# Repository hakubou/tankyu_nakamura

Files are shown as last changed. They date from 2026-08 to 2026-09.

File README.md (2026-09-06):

# 回転型倒立振子（Furuta pendulum）

Damiao **DM-J4310-2EC V1.1** と Quanser **QUBE-Servo 2** の振子モジュールを組み合わせた
回転型倒立振子。振り上げ（スイングアップ）から倒立保持までを自動で行う。

学校の探究課題として 2026 年 8 月に製作したもの。

## 到達点（2026-08-28 時点）

| 項目 | 実績 |
|---|---|
| スイングアップ成功率 | **82.8%**（トルク上限 0.8 N·m、29 回） |
| 振り上げ所要時間 | 中央値 1〜2 秒 |
| 倒立保持 | **最長 61.6 秒**（スイングアップからの連続動作） |
| 失敗の内訳 | すべて「アーム角が ±140° に到達」。**振子の姿勢制御自体の失敗は 0 件** |

制御周期は約 600 Hz。振子角は STM32 のハードウェアエンコーダで読み、
13 バイトのフレームで PC へ 1 kHz 送信する。制御則（オブザーバ＋LQR、
エネルギー整形則によるスイングアップ）はすべて PC 側の C# で動く。

## 構成

```
model/                          運動方程式の導出と制御則の設計（Python・オフライン専用）
  furuta_model.py                 SymPy による Lagrange 法の導出、線形化
  design_and_simulate.py          LQR / カルマンゲインの設計、非理想要素込みの検証
  friction_study.py               Karnopp 摩擦モデルでの検討
  pendulum_identification.py      振子パラメータの同定
  FurutaGains.cs                  ★生成物。csharp/src/DamiaoCan/ へコピーして使う

モータ制御プログラム一式_20260806/
  csharp/src/
    DamiaoCan/                    ライブラリ本体（CAN プロトコル、MIT フレーム、スケーリング）
    SwingUp/                      ★振り上げ→キャッチ→倒立保持
    BalanceControl/               ★倒立保持のみ
    PendulumTelemetry/            受信・状態推定の確認（トルクは送らない）
    SignCalibration/              座標系の符号を実測で決める
    FrictionTest/ TorqueCalibration/ OpenLoopSwing/ ほか  同定・校正ツール
  csharp/tests/DamiaoCan.Tests/   88 件。実機なしで通る

機構/                            アダプタの STL と生成スクリプト
引き継ぎ_20260828/
  01_引継ぎメモ_20260828.md       ★本体。経緯・設計・実測値・つまずいた点の全記録
  動作確認済みコード_20260828/     実機で動作を確認した版のスナップショット
  マイコンスケッチ/                STM32（Arduino）側。エンコーダを読んで送るだけ

ポスター/
  倒立振子_A0ポスター.html         ★発表用ポスター（A0 縦）。ブラウザで開いてそのまま印刷できる
  倒立振子_ポスターレイアウト案.html  面積配分を決めたワイヤーフレーム
```

## 動かす

`.NET SDK 10.0` が必要。

```
cd モータ制御プログラム一式_20260806/csharp
dotnet build
dotnet test
dotnet run --project src/SwingUp -- COM4 COM8 30 1.0 25 10
```

引数は左から「振子ポート・モータポート・SwingGain・振り上げトルク上限・
キャッチ角度・最小射影法の c・保持秒数」。**COM ポート番号は環境ごとに変わる。**

`model/FurutaGains.cs` を再生成したら、`csharp/src/DamiaoCan/` へのコピーが毎回必要。

## 実測した主なパラメータ

| 記号 | 値 | 備考 |
|---|---|---|
| J_r | 2.13×10⁻³ kg·m² | アーム慣性。高周波・小振幅加振で同定。質量からの概算の 5.3 倍で、差は減速機の反射ロータ慣性 |
| τ_c | 0.109 / 0.143 N·m | クーロン摩擦（正転／逆転）。30% の非対称あり |
| b_r | 0.027 N·m·s/rad | アーム側の粘性 |
| 振子の固有振動数 | 1.70 Hz | 実測。モデル予測 1.746 Hz と 3% 以内で一致 |
| 不安定極 | 11.05 rad/s | 時定数 90 ms |

## 設計上の方針

- 制御の実装はすべて **C#（.NET 10）**。Python は運動方程式の導出とゲイン計算のみに使い、
  **成果物は数値行列として C# に定数で埋め込む**。実行時に Python を呼ばない
- マイコン側は **エンコーダを読んで送るだけ**。制御ロジックは載せない
- MIT モードで `kp=kd=0` とし、`t_ff` だけでトルクを与える純トルク制御

## 安全上の注意

- **アームを 1 回転させない**（配線が引っ掛かる）
- 実行前にアームと振子の可動範囲に物・手・ケーブルが無いことを確認する
- 電源スイッチにすぐ手が届く状態で実行する
- 実行中に他のウィンドウをクリックすると、Windows の電源スロットリングで
  制御周期が 575 Hz → 130 Hz に落ちる。**計測中は裏で何も動かさない**

## ライセンス・帰属

- QUBE-Servo 2 の振子モジュールは借用品
- 引き継ぎ資料中の人名は伏せてある（メンバー A / B / C・指導教員）

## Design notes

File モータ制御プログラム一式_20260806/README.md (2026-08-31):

# DM-J4310-2EC V1.1 を Python から動かす手順

2026/8/6 に動作確認済み。同じ手順で誰でも再現できます。
不明点はメンバーA（<学籍番号>）まで。

---

## これは何か

Damiao のモータ **DM-J4310-2EC V1.1** を、PCから CAN 通信で回すためのプログラムです。
公式ソフト（達妙調試助手）は配布元が 404 で入手できなかったため、
**Python から直接 CAN フレームを送受信する方式**で実現しています。

実測: 速度モードで 0.5 rad/s を指定し、12.6秒で **359.5〜359.6度（＝1.00回転）**。
速度のばらつきはほぼ無し。

---

## 必要なもの

### ハードウェア

| 品目 | 備考 |
|---|---|
| DM-J4310-2EC V1.1 モータ | CAN ID は今回 **4** に設定済み |
| 24V 直流電源 | OMRON S8FS-G24024（240W級）を使用。8〜10A あれば十分 |
| USB-CAN 変換 | USB-CAN Analyzer V8.00（120Ω終端が内蔵されている） |
| 配線 | XT30(2+2) ケーブル（モータに付属） |

### 配線

```
        ┌── VCC / GND ──→ 24V電源
モータ ─┤  (XT30(2+2))
        └── CAN_H / CAN_L ──→ USB-CAN変換 ──USB──→ PC
```

※ GND は電源側と USB-CAN 側で共通にすること。

### ソフトウェア

```bash
pip install python-can pyserial
```

Python 3.14.6 で確認。CH340 のドライバが必要ですが、Windows 11 なら
USB-CAN を挿すと自動で入ることが多いです。

---

## 動かす手順

### 1. COMポート番号を調べる

デバイスマネージャー →「ポート (COM と LPT)」に
`USB-SERIAL CH340 (COM3)` のように表示されます。**この番号を控えてください。**
表示されない場合はドライバが入っていません。

### 2. 設定を自分の環境に合わせる

`demo_1回転.py` の冒頭を書き換えます。

```python
PORT     = "COM3"    # ← 手順1で調べた番号
MOTOR_ID = 4         # ← モータのCAN ID
```

### 3. 安全確認（必ず）

- モータが固定されているか
- 出力軸の回転範囲に手・物・ケーブルが無いか
- 電源スイッチにすぐ手が届くか

### 4. 実行

```bash
py demo_1回転.py
```

通信確認 → モード確認 → 1回転、まで自動で行います。

---

## つまずきポイント（先に読んでおくと時間を節約できます）

### 動かないときは、まず 24V 電源を疑う

**一番時間を無駄にした原因がこれです。** 電源が入っていないのに
「Enable が効かない」と悩み続けました。
モータのLEDが**赤＝失能、緑＝使能（通電中）**なので、まずLEDを見てください。

### MITモードでは kp を 0 にしてはいけない

`kp = 0` だと力が発生せず、モータはまったく動きません。
指令は届いていて、フィードバックも返ってくるのに動かないので原因が分かりにくいです。
今回は `kp = 20`、`kd = 2.0` で安定しました。

### 目標位置を遠くに置くと急加速する

MITモードで「29度先」を一度に指定したところ、非常に速く動いて危険でした。
目標との差が大きいほど強い力が出るためです。
**目標を5msごとに少しずつ進める**ことで、滑らかな低速回転になります
（`mit_move()` に実装済み）。

### 一定速度で回すだけなら速度モードが楽

| | MITモード | 速度モード |
|---|---|---|
| 指令 | 位置・速度・kp・kd・トルクの5要素 | 速度 (rad/s) のみ |
| 実装 | ゲイン調整と軌道生成が必要 | 値を1つ送るだけ |
| エンコーダ一周時 | 位置が飛んで誤停止した | 影響なし |

制御モードは **CAN経由で変更でき、フラッシュ保存すれば電源を切っても維持されます**
（`set_mode()` に実装済み）。今回は速度モード(3)に設定してあります。

### USB-CAN を開いた直後は 0.5 秒待つ

すぐに送信すると応答を取りこぼします。モジュール側で対処済みです。

### Enable / Disable はモータIDあてに送る

`0x104` や `0x204` に送っても受け付けられません。必ずモータID（今回は `0x004`）へ。

---

## ファイル構成

| ファイル | 内容 |
|---|---|
| `damiao_can.py` | 本体。接続・状態取得・使能/失能・モード読み書き・速度制御・MIT制御 |
| `demo_1回転.py` | 実行用。1回転させるデモ |
| `README.md` | このファイル |

## 簡単な使い方

```python
from damiao_can import Motor

with Motor(port="COM3", motor_id=4) as m:
    print(m.read_status())          # 状態を読む（動かない）
    m.spin(speed=0.5, turns=1.0)    # 0.5 rad/s で1回転
```

`with` を抜けると**必ず失能**されます。途中でエラーが出ても
モータは安全な状態（非通電）に戻るようになっています。

### よく使う操作

```python
m.read_status()                 # 位置・速度・エラー・温度を取得
m.scan()                        # 応答するモータのCAN IDを探す
m.read_mode()                   # 制御モードを確認 (1=MIT, 2=位置速度, 3=速度)
m.set_mode(3)                   # 速度モードへ変更して保存
m.spin(speed=0.5, turns=2.0)    # 2回転
m.spin(speed=-0.5, turns=1.0)   # 逆回転
m.mit_move(delta_rad=1.57)      # MITモードで90度動かす
```

---

## 主な仕様（データシートより）

- 定格 24V / 2.5A、ピーク 7.5A、過電流保護は 9.8A 以下推奨
- 定格トルク 3N·m、ピーク 7N·m、減速比 10:1
- 制御は CAN 1Mbps・標準フレーム
- Enable: `FF FF FF FF FF FF FF FC` / Disable: `FF FF FF FF FF FF FF FD`

詳しい背景や検証の経緯は、報告書 `モータ動作検証報告_20260806.pdf` を参照してください。

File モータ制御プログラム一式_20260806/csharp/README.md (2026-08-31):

# DM-J4310-2EC V1.1 を C# から動かす

研究室の方針に合わせ、Python 版（`../damiao_can.py` / `../demo_1回転.py`）を C# へ移植したものです。
ハードウェアの構成・配線・注意点は Python 版の [`../README.md`](../README.md) と同じなので、
**初めて動かす人は先にそちらを読んでください。**

---

## 必要なもの

### ハードウェア

Python 版とまったく同じです（DM-J4310-2EC V1.1 / 24V電源 / USB-CAN Analyzer V8.00 / XT30(2+2)）。

### ソフトウェア

- .NET SDK 10.0 以降
- CH340 のドライバ（USB-CAN を挿すと Windows 11 なら自動で入ることが多い）

Python も python-can も不要です。CAN アダプタのプロトコルは自前で実装してあります（後述）。

---

## 動かす手順

### 1. COMポート番号を調べる

デバイスマネージャー →「ポート (COM と LPT)」に `USB-SERIAL CH340 (COM3)` のように表示されます。

### 2. 安全確認（必ず）

- 24V電源が入っているか（**動かないときの原因はたいていこれ**）
- モータが固定されているか
- 出力軸の回転範囲に手・物・ケーブルが無いか
- 電源スイッチにすぐ手が届くか

### 3. 実行

```bash
dotnet run --project src/DemoOneTurn -- COM3
```

引数を省略すると `COM3` を使います。macOS / Linux なら `/dev/tty.usbserial-1140` のように指定してください。

通信確認 → モード確認 → 1回転、まで自動で行います。実行中に **Ctrl+C** を押すと、
その場で減速停止してから失能します（プロセスを即座に殺さないようにしてあります）。

### 4. 単体の exe にして配る場合

.NET が入っていないPCでも動く形にまとめられます。

```bash
dotnet publish src/DemoOneTurn -c Release -r win-x64 --self-contained -p:PublishSingleFile=true
```

---

## 簡単な使い方

```csharp
using DamiaoCan;

using var motor = new Motor("COM3", motorId: 4);

Console.WriteLine(motor.ReadStatus());        // 状態を読む（動かない）
motor.Spin(speed: 0.5, turns: 1.0);           // 0.5 rad/s で1回転
```

`using` を抜けると **必ず失能** されます。途中で例外が出てもモータは安全な状態（非通電）に戻ります。

### よく使う操作

| C# | Python 版 |
|---|---|
| `motor.ReadStatus()` | `m.read_status()` |
| `motor.Scan()` | `m.scan()` |
| `motor.ReadMode()` | `m.read_mode()` |
| `motor.SetMode(ControlMode.Velocity)` | `m.set_mode(3)` |
| `motor.Spin(speed: 0.5, turns: 2.0)` | `m.spin(speed=0.5, turns=2.0)` |
| `motor.Spin(speed: -0.5, turns: 1.0)` | `m.spin(speed=-0.5, turns=1.0)` |
| `motor.MitMove(deltaRad: 1.57)` | `m.mit_move(delta_rad=1.57)` |

---

## ファイル構成

| ファイル | 内容 |
|---|---|
| `src/DamiaoCan/Motor.cs` | 本体。使能/失能・状態取得・モード読み書き・速度制御・MIT制御 |
| `src/DamiaoCan/SeeedCanBus.cs` | USB-CAN Analyzer のシリアルプロトコル |
| `src/DamiaoCan/ICanBus.cs` | CANバスの抽象。別アダプタやテスト用の差し替え口 |
| `src/DamiaoCan/MotorFeedback.cs` | モータからの8バイトフィードバックの解釈 |
| `src/DamiaoCan/MotorScaling.cs` | MITフレームの値域と実数⇔整数の換算 |
| `src/DamiaoCan/ControlMode.cs` | 制御モード (1=MIT, 2=位置速度, 3=速度) |
| `src/DemoOneTurn/Program.cs` | 実行用。1回転させるデモ |
| `tests/DamiaoCan.Tests/` | 実機なしで動く検証（後述） |

---

## Python 版からの移植で変えたところ

### python-can に相当するものを自前で実装した

Python 版は `python-can` の `seeedstudio` バックエンドが USB-CAN Analyzer を扱っていましたが、
.NET には同等のライブラリがありません。そこで `SeeedCanBus.cs` に同じシリアルプロトコルを実装しています。

```
初期化   AA 55 12 [速度] [フレーム種別] [フィルタ4B] [マスク4B] [動作モード] 01 00×4 [CRC]
送受信   AA [0xC0|拡張<<5|RTR<<4|DLC] [ID 2B(標準) リトルエンディアン] [データ] 55
状態応答 AA 55 [18バイト]
```

依存は NuGet の `System.IO.Ports` だけです。

### 受信は必ず「まとめ読み」にしてある（重要）

`SerialPort.ReadByte()` は **1 回あたり約 1.16ms** かかります（macOS で実測）。
CAN フレーム 1 本はシリアル 13 バイトなので、Python 版と同じ「1 バイトずつ読む」構造で書くと
**1 本の受信に 15ms** も取られ、200Hz どころか 62Hz しか出ません。

`Read(buffer, 0, n)` でまとめ読みすれば同じ 13 バイトが 0.29ms で取れるので、
`SeeedCanBus.ReadByte()` は内部バッファに一括で貯めてから 1 バイトずつ払い出す作りにしてあります。
**ここを 1 バイト読みに戻すと制御周期が壊れます。**

実測値: 受信 15.08ms → 1.16ms、200Hz ループの実周期 16.3ms → 5.000ms。

### Ctrl+C で安全に止まるようにした

C# は既定だと Ctrl+C でプロセスが即座に終了し、`finally` の失能処理が走りません。
Python 版と同じ安全性を保つため、デモ側で Ctrl+C を捕まえて停止処理へ回しています。
`Spin()` と `MitMove()` は `CancellationToken` を受け取ります。

### 危険な入力を弾くようにした

- `Spin(speed: 0)` に回転数を指定すると、Python では所要時間がゼロ除算になります。
  C# では無限大になって**回り続けてしまう**ため、明示的に例外にしています。
- `MitMove` の速度が 0 以下の場合も同様です。

### CANバスをインターフェースにした

`Motor` は `ICanBus` に依存します。実機なしでテストできるほか、
別のCANアダプタを使う場合や1本のバスに複数台ぶら下げる場合にも差し替えられます。

### rad→deg の換算定数

Python 版は `57.2958`、C# 版は `180/π` を使っています。
差は4回転ぶん回しても 0.001度未満（エンコーダ分解能 0.0004度より小さい）で、実測に影響しません。

---

## 検証

実機が無くても、**Python 版とバイト単位で同じフレームを出すか**を自動で確認できます。

```bash
dotnet test
```

期待値は Python 版（`damiao_can.py` と python-can 4.6.1 の seeedstudio バックエンド）を
実際に走らせて採取したバイト列そのものです。80件すべて合格しています。

検証している範囲:

- アダプタの初期化フレーム（CRC 含む）
- 使能 / 失能 / 速度指令 / モード読み書き / フラッシュ保存の各パケット
- MITフレームの詰め方（値域外の頭打ちを含む）
- フィードバックの解釈と位置の rad 換算
- 受信パースの復帰（ゴミバイト・状態応答パケット・壊れたフレーム）
- エンコーダが一周したときの差分補正
- 例外や中断が起きても最後に必ず失能を送ること

**実機での動作確認はまだ行っていません。** 上記はあくまで「Python 版と同じバイト列を出す」ことの
確認までです。初回はモータを固定し、電源スイッチに手を届く状態で試してください。

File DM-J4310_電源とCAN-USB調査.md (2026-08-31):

# DM-J4310-2EC V1.1 — 電源(24V)とCAN-USB変換 調査メモ

対象モーター: DAMIAO（达妙）**DM-J4310-2EC V1.1**（QDDサーボ関節モーター / 24V版）
作成日: 2026-07-06

---

## 1. まとめ（結論）

| 項目 | 推奨・目安 |
|---|---|
| 電源電圧 | **24V**（動作範囲 15〜32V） |
| 電源電流（1個・実用） | **最低 3A、余裕をもって 5〜10A** を推奨 |
| 電源電流（1個・ピーク吸収） | 瞬間 7.5A まで流れうる → **10A級電源**が安心 |
| CAN-USB変換 | **DAMIAO純正 USB-to-CAN（USB2CAN）モジュール**が最も確実 |
| CANボーレート | **1 Mbps 固定**（標準フレーム） |
| 終端抵抗 | CANバス両端に **120Ω** |

---

## 2. 24V電源に必要な電流

### 2.1 モーター単体の消費電流

公式・代理店資料の数値（24V版）:

| 電流の種類 | 値 | 備考 |
|---|-----|---|
| **定格電流（電源側 / バス電流）** | **2.5 A** | 定格トルク3N·m時の目安 |
| **ピーク電流（電源側）** | **7.5 A** | 瞬間・加速/急停止時 |
| 定格相電流（Rated Phase Current） | 3.7 A | モーター巻線に流れる電流 |
| ピーク相電流（Peak Phase Current） | 7.2 A | 巻線ピーク |

> ⚠️ 「相電流（phase current）」と「電源電流（bus current）」は別物です。
> 電源（ACアダプタ/安定化電源）の容量選定には、**電源側の電流（定格2.5A / ピーク7.5A）** を使います。

### 2.2 電力に換算

- 定格: 24V × 2.5A ≒ **60 W**
- ピーク: 24V × 7.5A ≒ **180 W**

### 2.3 電源容量の選び方（推奨）

**モーター1個の場合**
- 動作確認・デバッグ用途: **24V / 3〜5A（72〜120W）** で可
- 負荷をかけた運用: 突入・加速でピークが出るため **24V / 10A（240W）** クラスが安心
  - 安価な安定化電源やベンチ電源なら「24V 10A」表記のものが定番

**複数個（ロボットアーム等）の場合**
- 最悪ケース = ピーク電流の合計: `モーター数 × 7.5A`
  - 例）4軸アーム → 4 × 7.5A = 30A（＝ 24V 30A ≒ 720W）
  - 例）6軸アーム → 6 × 7.5A = 45A
- 実際は全軸が同時に最大ピークになることは稀なので、
  現実的には **「定格合計 ＋ 余裕」** で設計することが多い:
  - 例）6軸 → 定格 6 × 2.5A = 15A → **24V 20A（480W）** 程度を選定し、大電流の瞬間はコンデンサ/電源のマージンで吸収
- **重要（公式ガイダンス）**: 複数モーターでは**専用の電源分配基板（Power Board）を用意し、制御PC/Jetson等の電源とモーター電源を分離**すること。

### 2.4 その他の電気的注意

- 過電圧保護: 推奨 **32V以下**
- 低電圧保護: 推奨 **15V以上**
- 過電流保護: 推奨 **9.8A以下**
- 温度保護: ドライバ 120℃ / コイル 推奨100℃以下
- 48V版も存在（動作範囲15〜52V）。24V版とは別品番なので購入時に要確認。

---

## 3. CAN-USB変換（上位機との接続）

### 3.1 通信仕様

- 制御インターフェース: **CAN @ 1 Mbps（標準フレーム、ボーレート固定）**
- パラメータ設定インターフェース: **UART @ 921600 bps**
- 制御モード: MITモード / 速度モード / 位置モード（台形加減速対応）

### 3.2 変換機の選択肢

#### (A) DAMIAO純正 USB-to-CAN（USB2CAN）モジュール ★推奨
- モーターと同時購入できる純正デバッグツール
- 超小型（約 **39 × 18 mm**）、64KB オンボードバッファ、CANアナライザ機能内蔵
- ボーレート 1000 kbps〜（可変）、タイマ送信対応
- Windows用「**DAMIAO デバッグアシスタント（上位机 / Debugging Assistant）**」で
  ID設定・モード切替・モニタリングが可能
- USB↔UART変換も兼ねるため、パラメータ設定（921600bps）にも使える

#### (B) 汎用USB-CANアダプタ
- **CANable 2.0 / candleLight系**（Linuxのsocketcanで `can0` として使える）
  - `slcan` またはネイティブ candleLight ファームで動作
- **CAN FD対応アダプタ**（LeRobot/OpenArms構成では CAN FD を使用）
- 中華系「USB-CAN / USB2CAN アナライザ」も可（ドライバ・ボーレート設定に注意）

### 3.3 物理接続（純正モジュールの例）

DAMIAOのデバッグツールを使う典型的な配線:

1. **電源＋CAN通信端子**: モーター側の **XT30(2+2)-F** コネクタケーブルで
   USB-to-CANツールへ接続（電源とCAN-H/CAN-Lが一体化したコネクタ）
2. **デバッグ用シリアル（UART）**: **GH1.25 3ピン**ケーブルでシリアルポートを接続
3. **24V電源**: モーターへ別途供給（XT30側の電源ラインへ）
4. USBをPCへ接続 → デバッグアシスタントを起動 → 該当シリアルポートを選択 → 通電

> ⚠️ **H/L反転の注意**: 一部ホスト基板（例: Seeed reComputer Mini）では
> CAN-H / CAN-L のピン配置がモーター側と逆になっている。接続不良時は H/L の入替を確認。

### 3.4 CANバス配線の基本

- **CAN-H / CAN-L / GND** の3線を各モーターへデイジーチェーン接続
- バスの**両端に120Ωの終端抵抗**（片側はアダプタ内蔵の場合あり）
- 複数モーターは **CAN IDを重複しないよう個別設定**（純正ツールで設定）
  - OpenArms/LeRobotの慣例: 送信ID `0x0N` / 受信ID `0x1N`（N=関節番号）

### 3.5 Linux（socketcan）での設定例（LeRobot/OpenArms）

```bash
# can-utils をインストール
sudo apt-get install can-utils

# CAN FD（推奨 / OpenArms）
sudo ip link set can0 down
sudo ip link set can0 type can bitrate 1000000 dbitrate 5000000 fd on
sudo ip link set can0 up

# 通常CAN（FDなし）
sudo ip link set can0 type can bitrate 1000000
sudo ip link set can0 up

# 疎通確認
candump can0
```

- Windowsは純正「デバッグアシスタント（上位机）」でGUI操作が容易
- LeRobotのDamiao対応は**現状Linuxのみ**（OpenArms用CANアダプタのドライバがLinux専用）

---

## 4. 購入時のチェックリスト

- [ ] モーターの電圧版（**24V** or 48V）を確認
- [ ] 24V電源: 1個なら **24V 5〜10A**、多軸なら電流を積算して選定
- [ ] **電源分配基板**（多軸時）と制御系電源の分離
- [ ] **USB-to-CANモジュール**（純正 or CANable等）
- [ ] **XT30(2+2)** 電源+CANケーブル、**GH1.25 3ピン** UARTケーブル
- [ ] **120Ω終端抵抗**（バス両端）
- [ ] Windows: デバッグアシスタント / Linux: can-utils・socketcan

---

## 5. 参考文献

- [DAMIAO 公式製品ページ DM-J4310-2EC V1.1](https://damiao.enactic.ai/products/hardware/dm-j4310-2ec-v1.1/)
- [DM-J4310-2EC V1.1 減速モーター ユーザーマニュアル V1.0 (PDF, Seeed)](https://files.seeedstudio.com/products/Damiao/DM-J4310-en.pdf)
- [DM-J4310-2EC V1.1 Gear Motor User Manual V1.0 (PDF, sharingwin)](https://sharingwin.com/wp-content/uploads/2025/09/DM-J4310-2EC-V1.1-Gear-Motor-User-Manual-V1.0.pdf)
- [Damiao Series Motors — Seeed Studio Wiki](https://wiki.seeedstudio.com/damiao_series/)
- [Damiao Motors and CAN Bus — Hugging Face / LeRobot](https://huggingface.co/docs/lerobot/damiao)
- [DAMIAO Brushless Servo Joint Motor Debugger USB to CAN MIT Module — OpenELAB](https://openelab.io/products/damiao-brushless-servo-usb-can)
- [DAMIAO CAN Debugger USB-to-CAN — Foxtech](https://store.foxtech.com/can-debugger-usb-to-can-communication-debug-tool-for-mit-servo-motors/)
- [DAMIAO DM-J4310-2EC — AIFITLAB（仕様・24V/48V版）](https://aifitlab.com/products/damiao-dm-j4310-2ec-v1-1-servo-motor)
- [USB to CAN FD Converter (Canable 2.0ベース) — Amazon](https://www.amazon.com/Converter-Adapter-Based-Canable-Supports/dp/B0F9F9J3WN)

> 注: 電流値・接続仕様は代理店/版により表記差があります。実機導入時は必ず付属の
> 最新ユーザーマニュアルと安全定格を確認してください。

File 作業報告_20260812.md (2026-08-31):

# 作業報告 2026/08/12（水）

**件名**: DM-J4310-2EC を用いた回転型倒立振子（Furuta pendulum）

ロードマップ上の **Day 2 を完了し、Day 3 を前倒しで完了**した。
あわせて機構設計（アダプタ・校正治具）と振子パラメータの同定まで進んだ。

---

## 1. 実機作業（モータ）

| 項目 | 結果 |
|---|---|
| MIT モードへ移行 | 完了。フラッシュ保存し、電源再投入後も `CTRL_MODE=1` を維持 |
| レジスタ照合 | `P_MAX=12.5` / `V_MAX=30` / 減速比 `10:1` を CAN 経由で直読し、コードの定数と一致を確認 |
| **T_MAX 変更** | **10 → 2.0 N·m**。12bit 分解能が 4.9 → **0.98 mN·m** と5倍細かくなった |
| 逆駆動テスト | 合格。失能時と使能時（トルク0）で感触に差が無く、寄生トルクなし |
| 静止摩擦 | **0.147 N·m**（T_MAX 変更後に再測して 0.137、7%以内で整合） |
| 動摩擦 | **0.126 N·m**（正転 0.109 / 逆転 0.143、30% 非対称） |
| 粘性摩擦 | **0.027 N·m·s/rad** |
| 制御周期 | **300 Hz に決定**（下表） |

### 制御周期の実測（素のモータ、各12秒）

| 目標 | 実測平均 | 標準偏差 | 95%点 | 最大 | 取りこぼし |
|---|---|---|---|---|---|
| 200 Hz | 5.000 ms | 0.820 | 5.92 | 21.7 | 0% |
| **300 Hz ←採用** | **3.333 ms** | **0.563** | **3.75** | 21.8 | 0% |
| 400 Hz | 2.500 ms | 0.851 | 3.61 | 33.1 | 0% |
| 500 Hz | 2.294 ms ✗ | 1.158 | 3.52 | 38.3 | 0% |

500 Hz は追いつけず実質 436 Hz。**USB-CAN の往復遅延が約 2.3 ms** で、これが上限を決めている。
振子の時定数（約 90 ms）に対して常用遅延 5 ms は 6% であり、制御上問題ない。

### T_MAX 変更の検証方法

レジスタを書き換えただけでは、指令とフィードバックの解釈が本当に整合しているか分からない。
そこで**既に測ってある静止摩擦を測り直し**、同じ物理量が同じ値で出るかを確認した。
不整合なら 5 倍または 1/5 倍にずれるはずのところ、0.147 → 0.137 と 7% 以内で一致したため整合と判断。
副次的に、測定のばらつきが 0.133〜0.147 → 0.122〜0.129 と狭まり、分解能向上が実測精度にも表れた。

**変更はモータ側 → コード側の順で行った。** 逆順だと「コードは小さい T_MAX、モータは大きい T_MAX」
となり、同じ指令値が数倍のトルクとして解釈されて危険なため。

---

## 2. 制御ソフト（C# / .NET 10）

### ライブラリに追加したもの

| API | 内容 |
|---|---|
| `Motor.TorqueCommand(torqueNm)` | 純粋トルク指令。`kp=kd=0` を型で保証 |
| `Motor.ReadFeedback(timeout)` | 定周期ループ用のフィードバック読み出し |
| `Motor.ReadParameter / ReadParameterSingle / ReadParameterUInt32` | レジスタ読み出しの汎用化 |
| `Motor.WriteParameterSingle / SaveToFlash` | レジスタ書き込みとフラッシュ保存 |
| `Motor.VerifyScaling()` | **トルクを出す前にレジスタと定数の一致を検証する安全網** |
| `RegisterId` | パラメータ番号の定義（7〜23） |

### 設計上の修正

`Motor.BuildMitFrame` がグローバル定数（`MotorScaling`）に暗黙依存していたため、
T_MAX を変更すると「Python 版と同じバイト列を出す」という回帰テストの前提ごと壊れた。
**値域を引数で渡せるようにし、詰め方の検証と値域設定を分離**した。

### 作成したツール

| ツール | 用途 |
|---|---|
| `SetControlMode` | モード確認・変更、レジスタ照合、T_MAX 変更 |
| `BackdriveTest` | 逆駆動テスト、制御周期のジッタ計測 |
| `FrictionTest` | 静止摩擦 / 動摩擦・粘性の測定（3モード） |
| `TorqueCalibration` | トルクスケール校正、重力補償デモ（未実行） |

**単体テスト 88 件すべて合格。**

---

## 3. モデリングと制御設計

### 実施内容

- **SymPy による Furuta の運動方程式導出**（手計算では Coriolis 項の符号を誤るため）
- 平衡点での線形化 `A`, `B`。可制御性ランク 4/4
- LQR（Bryson の法則）と定常カルマンフィルタの設計
- **実測の遅延・ジッタ・量子化・非対称クーロン摩擦をすべて入れた非線形閉ループ検証**
- 摩擦モデルを `tanh` から **Karnopp（真の固着あり）** に差し替えた再検証
- 摩擦補償の効き・アーム慣性についての感度解析

### 振子パラメータの同定（実測から）

| パラメータ | 値 | 出所 |
|---|---|---|
| 振子全長 | 128.70 mm | 実測 |
| ピボットより上 | 7.0 mm | 実測 |
| **l_p（ピボット→重心）** | **57.35 mm** | 上記から算出 |
| **J_pivot** | **1.123×10⁻⁴ kg·m²** | 自由振動 T=0.5730 s から |
| **J_p（重心まわり）** | **3.33×10⁻⁵ kg·m²** | 同上 |
| **b_p（振子軸の粘性）** | **2.45×10⁻⁵ N·m·s/rad** | 対数減衰 δ=0.0624/往復 |
| 不安定極 | **11.17 rad/s（時定数 90 ms）** | モデルから |

**幾何形状からの予測（J_pivot = 1.121×10⁻⁴）と周期からの逆算が 0.17% で一致。**
「一様な棒が端から 7 mm で吊られている」という仮定が正しいことの裏付けとなった。

なお、測定された「20往復で 5.73 秒」は物理的にありえない（質量が全部重心に集中していても
J_pivot は 7.9×10⁻⁵ 以上あり、T=0.285 秒には 2.8×10⁻⁵ が必要）。
**10往復（片道20回）と解釈**すると幾何予測と 0.2% で一致するため、そちらを採った。

### 検証結果（Karnopp 摩擦、実測パラメータ）

許容トルク（Bryson の重み）を掃引した結果、**0.005〜0.01 N·m 付近に明確なスイートスポット**があり、
そこでリミットサイクルは **0.15〜0.5°**。
L_r を 85〜120 mm、J_r を 0.3〜3.0 g·m² に振っても成立する。

⚠️ **ゲイン感度が高い。** 許容トルクを 0.01 → 0.02 に変えるだけで 0.24° → 5.37° と 20 倍以上悪化する
（非単調）。実機ではシミュレーションの最適点が最適とは限らないため、
Day 6 では対数的に振って探す前提でいること。

---

## 4. 機構設計

### QUBE モジュール取付アダプタ（4部品）

| 部品 | 厚み | 役割 |
|---|---|---|
| スペーサリング | 4 mm | 回転フランジ（Ø34.95）と固定ハウジング（Ø57）の干渉回避 |
| ベース板 | 6 mm | モータ出力フランジへ固定。M4 締結穴、Ø4 ピン穴 |
| クレードル板 | 20 mm | 外開き U 字溝。**溝の壁でトルクを受ける** |
| キータイル | 3.5 mm | モジュールの窪み（23×23）を埋め、形状拘束と磁石保持を兼ねる |

**トルク伝達は磁石ではなく形状とネジで受ける設計とした。** PLA はボルト予圧でクリープするため、
摩擦だけに頼る締結は経時的に緩み、「制御中に時々ズレる」という発見しにくい壊れ方をする。

- ヨー（制御トルクの方向）: 溝の壁 ＋ Ø4 位置決めピン
- 締結: モジュール側面の M4 ネジ穴へ下から直結
- 磁石: 保持のみ

### トルク校正用アーム

左右対称形状（全長 170 mm、錘穴は r = 75 mm）。
**対称にすることでアーム自身の重力トルクが完全に相殺され、先端に付けた錘の m·g·r だけが残る。**
校正の基準そのものが正確になる。A1 mini（180 mm）に収まる寸法に設計変更済み。

### 自動検証

STL 生成スクリプトには寸法の整合性チェックを実装した。
本日の作業中、**穴同士の干渉・造形サイズ超過・スペーサとハブ径の不整合・
M4 穴と M3 スロットの干渉など、計 5 件を自動検出**して手戻りを防いだ。
生成物はすべて多様体チェックを通過し、三角形分割の総面積が解析値と誤差 0.0000 mm² で一致。

---

## 5. 判断を変更した点（重要）

本日の検証により、以前の判断のうち **4 件が誤りと判明**した。記録として残す。

### ① 「摩擦が必要トルクの10倍あるのでアーム延長 300 mm が必須」→ 誤り

必要な定常トルク（0.014 N·m）と摩擦（0.126 N·m）を比べて「10倍だから無理」と判断していたが、
**モータは 2.0 N·m 出せる**。摩擦は越えられない壁ではなく打ち消すべき外乱であり、
制御器は必要なだけトルクを積み増して振り切ればよい。

比べるべきは「必要な定常トルク 対 摩擦」ではなく「**使えるトルク 対 摩擦**」だった。

素の寸法で転倒した最初のシミュレーションは、**改造後のプラント用に調整したゲインを
そのまま使った不公平な比較**であり、対照実験（摩擦ゼロ）でも 0.04 秒で転倒した。
素の寸法はトルク応答が 10 倍敏感（B[3] = −2602 rad/s²/N·m）なため、
同じ重みでは閉ループ極が 530 rad/s まで上がり離散化で不安定化していた。

**→ アーム延長ブラケット（215 mm）、錘（150 g）、アルミ加工は不要になった。**

### ② 「摩擦補償は必須」→ 必須ではない

Karnopp モデル（真の固着あり）での検証では、**補償なしでも成立**した（1.69°）。
さらに、**固着ありの方が tanh 近似よりリミットサイクルが小さい**（0.41° 対 0.96°）。
静止摩擦は関節を実際に止めるため、「その場に留める」問題では味方に回る。

スティクションが有害なのは追従制御や精密位置決めであって、倒立振子では逆に働く。

ただし前滑り変位や摩擦の履歴は Karnopp でも表現できないため、補償は入れておく方針は維持する。

### ③ 「スリップリングが必要」→ 不要

エンコーダのケーブルは**エンコーダ本体（ブロック側）から出ており、回転するのは銀の丸棒**。
振子が何回転してもケーブルは回らない。アームもスイングアップ中に往復するだけで連続回転しない。
**サービスループ（たるみ）で足りる。**

### ④ 「取り付け平面を下に伏せて板に載せる」→ 不可能

取り付け平面は**円筒に 3.5 mm 掘り込まれた窪み**であり、円筒面の方が外側に出ている。
平らな板に置いても平面は接触しない。
M4 ネジ穴が円筒面にあるという指摘で判明。**円筒面で受け、M4 で締結する構成に変更した。**

---

## 6. 未解決事項

| 項目 | 内容 |
|---|---|
| Ø4 ピン穴の角度 | M3 穴と一直線か中間か。**目視確認のみで判明する**（半径差 1.35 mm のため同一角度だと穴が重なる） |
| 溝の嵌合 | `gauge` を印刷して現物合わせ |
| L_r（実効アーム長） | 組み立て後に実測。85〜120 mm の範囲では結果が変わらないことは確認済み |
| モジュールの質量 | `J_r` の推定精度が上がる |
| トルクスケール校正 | `TorqueCalibration` は作成済み、実行は腕と錘（340〜510 g）待ち |
| `FurutaGains.cs` | 実測パラメータでの再生成が必要 |

---

## 7. 成果物

```
探求/
├── CLAUDE.md                          プロジェクト方針（C# で設計する等）
├── 倒立振子_ロードマップ.md            全9回の計画と実測値
├── 作業報告_20260812.md               本書
├── model/
│   ├── furuta_model.py                SymPy による導出＋線形化
│   ├── design_and_simulate.py         LQR・カルマン設計＋閉ループ検証
│   ├── friction_study.py              Karnopp 摩擦での再検証
│   ├── pendulum_identification.py     自由振動からのパラメータ同定
│   └── FurutaGains.cs                 C# へ埋め込む定数
├── 機構/
│   ├── ハードウェア設計_引き継ぎ書.md   共同作業者向け
│   ├── generate_calibration_arm.py    校正アームの STL 生成
│   ├── generate_qube_adapter.py       アダプタ4部品の STL 生成
│   └── *.stl                          生成物
└── モータ制御プログラム一式_20260806/csharp/
    ├── src/DamiaoCan/                 ライブラリ（API 追加）
    ├── src/SetControlMode/            モード・レジスタ操作
    ├── src/BackdriveTest/             逆駆動テスト・ジッタ計測
    ├── src/FrictionTest/              摩擦測定
    ├── src/TorqueCalibration/         トルク校正・重力補償
    └── tests/                         88 件合格
```

---
---

# 【後半】機構設計の確定と、実機での共振測定

前半の報告後にさらに進んだぶんを追記する。

## 8. ★本日最大の成果★ 実機で振子の固有振動数を測定した

**振子エンコーダが未着荷（ジャック待ち）のまま、モータ自身のフィードバックだけで
振子の固有振動数を測定することに成功した。**

### 方法

アームを MIT モードの位置制御で正弦波駆動し、周波数を掃引する。
振子が共振すると反力がアームに返り、位置制御の負荷が変わる。
つまり**振子側にセンサが無くてもモータ側の数値に痕跡が出る**。

### 結果（±8°、kp=20、1.30〜2.30 Hz）

| 周波数 [Hz] | 追従誤差RMS [deg] | トルクRMS [N·m] |
|---|---|---|
| 1.30 | 0.730 | 0.1319 |
| 1.50 | 0.790 | 0.1354 |
| **1.60** | 0.841 | **0.1437 ← ピーク** |
| 1.70 | 0.855 | 0.1409 |
| **1.80** | 0.874 | **0.1395 ← ディップ** |
| 1.90 | 0.914 | 0.1416 |
| 2.10 | 0.961 | 0.1448 |
| 2.30 | 1.024 | 0.1498 |

慣性負荷による単調増加（ω² に比例）の上に、**ピーク（1.60）とディップ（1.80）の対**が乗っている。
これは基礎加振された振子の典型的な挙動で、共振点より下では振子が同相に動いて実効慣性を増やし、
上では逆相になって減らす。**遷移点＝固有振動数は 1.70 Hz。**

### 意義

**自由振動から予測した 1.745 Hz と 3% 以内で一致した。** これにより3点が同時に裏付けられた。

1. **モデルが正しい** — 机上の予測が実機で再現された
2. **アダプタがトルクを伝えている** — 滑っていれば振子と結合せず、この構造は現れない
3. **組み立てが健全** — 結束バンドでの仮固定でもこの加振レベルでは十分

ロードマップ上は Day 5 のパラメータ同定に相当する内容を、実機で前倒しできたことになる。

### 併せて確認したこと

| テスト | 結果 |
|---|---|
| 弱加振（±3°、1.0 Hz、6秒） | 追従誤差 1.33 → 1.28°。**滑り・ドリフトなし** |
| 中加振（±5°、1.75 Hz、8秒） | 誤差 0.75° で安定 |
| 共振加振（±10°、1.68 Hz、16秒） | 誤差 0.98° で定常。発散も劣化もなし |

追従誤差が摩擦の不感帯で決まることも確認できた
（kp=4 では 1.3°、kp=15 では 0.75°、kp=20 では 0.98°／振幅増）。
摩擦 0.126 N·m を kp で押すのに必要な偏差 τ_c/kp とよく一致する。

### 限界

振子（24 g）の反力は振幅 0.5 rad でも **8 mN·m** 程度で、摩擦 126 mN·m の 7% しかない。
そのためトルク RMS の変化は 3% 程度にとどまり、**信号は弱い**。
また固定周波数では振幅増加に伴う固有振動数の低下を追えないため、真上までは上がらない。
**本来のスイングアップには振子角の計測が必須**であり、これはエンコーダ着荷後の課題。

---

## 9. モータ図面の確定

公式図面とメンバーA氏の実測データにより、出力側の寸法がすべて確定した。

| 項目 | 値 |
|---|---|
| 回転する出力フランジの外径 | **Ø34.95**（実測） |
| ボルト円（PCD） | **Ø27**、6×M3、深さ 5mm |
| 位置決めピン穴（大） | 3×Ø4（+0.02/+0.04）、PCD **Ø24.30** |
| 位置決めピン穴（小） | 2×Ø3（+0.02/+0.04）、深さ 5mm、基準から 15° |
| フランジの出っ張り | **1 mm**（実測。図面の 45/46 の差と一致） |
| 固定側ハウジング | Ø50 に 6×M3（**使わない**） |

図面の「Ø24.30」は位置決めピンの配置円であることが判明した。

---

## 10. アダプタ設計の確定（v8）

### 最終構成（4部品）

| 部品 | 寸法 | 体積 | 役割 |
|---|---|---|---|
| スペーサリング | Ø34 × 4 | 2.3 cm³ | 固定ハウジングとの干渉回避（隙間 5mm） |
| **ベース板** | Ø86 × 8 ＋ パッド 3.3 ＋ ペグ 5 | — | モータへ固定。**パッドとペグを一体成形** |
| 側面レール ×2 | 30 × 12 × 20 | 6.8 cm³ ×2 | 円筒を横から挟んでヨーを止める |
| 校正アーム＋錘 | 全長 170 / Ø60 | 28 / 81 cm³ | トルクスケール校正用 |

### トルクの経路

```
モータ → ベース板 → 一体パッド（23×23）→ 窪みの壁 → モジュール
                  ＋ M4 締結（R37.6、下から）
                  ＋ 側面レール（横方向）
```

**磁石にはトルクを持たせていない。** PLA はボルト予圧でクリープするため、
摩擦だけに頼る締結は経時的に緩み、「制御中に時々ズレる」という
発見しにくい壊れ方をする。形状とネジで受ける設計とした。

### 主要寸法

- ピボット高さ **26.0 mm**（スペーサ4 ＋ ベース8 ＋ 円筒半径14）
- 振子先端はモータ背面より **49.7 mm 下** → **固定治具は机から 70 mm 以上持ち上げる**
- 板厚 8mm は M4 ネジ（全長19.4／頭4.1）に合わせた値。ねじ込み 7.3mm

---

## 11. 判断を変更した点（後半ぶん）

### ⑤ 「取り付け平面を下に伏せて板に載せる」→ 不可能

取り付け平面は**円筒に 3.5 mm 掘り込まれた窪み**であり、円筒面の方が外側に出ている。
平らな板に置いても平面は接触しない。
**M4 ネジ穴が円筒面にあるという指摘で判明した。**
→ 円筒面で受け、M4 で締結する構成に変更。

### ⑥ 「キータイルを別部品にする」→ ベース板と一体成形へ

別部品にすると
- タイルの固定ネジがベース板の他の穴と干渉する
- **そもそもタイルをベース板に固定しないとトルクの経路にならない**（タイルが浮いていると
  「モジュール ⇄ タイル」は結合しても「タイル ⇄ ベース板」が結合しない）

の二つの問題が出た。一体成形にして両方解消。
そのために**多段押し出しのメッシャを新規実装**した。

### ⑦ 「クレードル円板」→ 側面レール2個へ

モジュール後端の形状が不定であり、そこに触れる必要もない（横方向だけ支えれば足りる）。
**印刷量が 93 cm³ → 13.6 cm³ と 1/7 になった。**

### ⑧ 「校正には 340〜510 g の金属錘が必要」→ PLA 製 100 g で足りる

「摩擦の2〜3倍必要」の根拠は、摩擦の正逆非対称（0.109 対 0.143）が
上げ下げの平均に −0.017 N·m の系統誤差として残ることだった。
**この非対称量は実測済みなので解析側で差し引ける。**

循環論法にはならない。トルクスケールが k 倍ずれていれば摩擦の実測値も
同じく k 倍ずれるため、補正後の比はきれいに 1/k になる。

→ 必要質量が 100 g まで下がり、**3Dプリント製の錘（Ø60×28.9、81 cm³）で校正可能**になった。

---

## 12. 実装した機能（後半ぶん）

| 対象 | 内容 |
|---|---|
| `generate_qube_adapter.py` | **多段押し出しメッシャ**（入れ子の段を積む立体） |
| 同上 | 寸法検証を拡充。本日 M4 穴の板外飛び出しなど計 6 件を自動検出 |
| `generate_calibration_arm.py` | PLA 製錘の生成（目標質量から寸法を逆算） |
| `TorqueCalibration` | 摩擦の非対称による系統誤差の補正（`--friction-pos/neg`） |
| **`OpenLoopSwing`（新規）** | 振子エンコーダ不要の共振加振・周波数掃引 |

単体テストは **88 件すべて合格**を維持。

---

## 13. 未解決事項（更新）

| 項目 | 状況 |
|---|---|
| 振子エンコーダの配線 | **ジャック待ち**。これが本番の律速 |
| Ø4 ピン穴の角度 | 目視確認のみで判明する（M3 穴と一直線か中間か） |
| 新ベース板の印刷 | 現状は結束バンドでの仮固定。加振レベルでは問題ないが本番前に要交換 |
| 溝・ペグの嵌合 | ゲージとキータイルで現物合わせ |
| トルクスケール校正 | ツール・治具とも完成。錘の印刷待ち |
| `FurutaGains.cs` | 実測パラメータでの再生成が必要 |
| 固定治具 | 机から 70 mm 以上持ち上げる必要がある。未設計 |

---

## 14. 所感

本日は「実機で確かめられることは全部確かめる」方針で進めた結果、
**机上の判断のうち 8 件が誤りと判明**した。いずれも実測または対照実験で覆っている。

特に ①（摩擦10倍だからアーム延長必須）と ⑤（平面を下に伏せる）は、
そのまま進めていれば**アルミ加工と 215mm ブラケットの製作、
および組めない部品の印刷**という形で顕在化していた。

一方、**モデルの予測精度は高い**。振子パラメータの同定では幾何予測と周期からの逆算が
0.17% で一致し、固有振動数の実機測定でも予測と 3% で一致した。
モデルは信頼してよく、疑うべきは前提条件の方だった、というのが本日の教訓。

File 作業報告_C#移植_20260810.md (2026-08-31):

# 作業報告：モータ制御プログラムの C# 移植と制御周期の実測

- 報告日: 2026/08/10
- 対象: Damiao DM-J4310-2EC V1.1（CAN ID = 4）
- 内容: 2026/08/06 の Python 実装を C# へ移植し、実機で動作確認・制御周期を実測

---

## 0. 要旨

- Python 版（`damiao_can.py` / `demo_1回転.py`）を C# へ全面移植し、**実機で 1 回転の動作を確認**した。
- **200Hz（5ms 周期）の制御ループは、標準偏差 3μs で安定して回せる**ことを実測で確認した。
- ただし途中で **1 周期あたり 15ms を食う実装上の落とし穴**があり、これを直して初めて 200Hz が出た（詳細は §5）。
- 律速は言語ではなく **USB-CAN アダプタの往復時間（約 1.8ms/周期）**。500Hz が実用上限、1kHz は届かない。

---

## 1. 制御周期【必須】

### 1.1 測定条件

- 使能コマンドは送らず、失能状態で速度指令フレーム（0x204、速度 0.0）を定周期で送信し、
  同じループ内でフィードバックを受信した。**モータは回していない。**
- 1 周期＝「送信 → 受信取り込み → 次周期まで待機」。各周期の実測間隔を全数記録した。
- `GCSettings.LatencyMode = SustainedLowLatency`、スレッド優先度 Highest を設定。
- 200Hz は 2000 サイクル（10 秒）、それ以外は各 3 秒相当。

### 1.2 待機方式の比較（目標 200Hz = 5.00ms、2000 サイクル）

| 待機方式 | 平均 | 中央 | 最小 | 最大 | 標準偏差 | p95 | p99 |
|---|---|---|---|---|---|---|---|
| **スピン待ち** | **5.000** | 5.000 | 4.956 | **5.044** | **0.003** | 5.001 | 5.011 |
| ハイブリッド | 5.000 | 5.000 | 1.359 | 9.761 | 0.140 | 5.005 | 5.118 |
| `Thread.Sleep` | 7.091 | 6.910 | 5.386 | 52.753 | 1.783 | 7.987 | 8.526 |

単位はすべて ms。

- **スピン待ち（`Stopwatch` を見ながら待つ）が圧倒的に安定。ジッタは最大でも ±44μs、σ=3μs。**
  ただし 1 コアを 100% 占有する（8 コアあるので実用上は問題なし）。
- ハイブリッド（残り 2ms までは `Sleep(1)`、最後だけスピン）は CPU を空けられるが、
  最大 9.76ms＝1 周期スキップ相当が発生する。
- **`Thread.Sleep` 単独は制御周期の生成に使えない。** 平均が 42% も伸び、最大 52.75ms に飛ぶ。

### 1.3 周波数を変えた場合（スピン待ち）

| 目標 | 平均 | 中央 | 最小 | 最大 | 標準偏差 | p99 | 判定 |
|---|---|---|---|---|---|---|---|
| 100Hz (10.00ms) | 10.000 | 10.000 | 9.843 | 10.156 | 0.022 | 10.125 | 余裕 |
| **200Hz (5.00ms)** | **5.000** | 5.000 | 4.982 | 5.018 | **0.002** | 5.010 | **余裕** |
| 500Hz (2.00ms) | 2.053 | 2.000 | 0.816 | 10.332 | 0.497 | 4.647 | 実用上限 |
| 1000Hz (1.00ms) | 1.662 | 1.180 | 0.031 | 20.488 | 0.947 | 4.810 | **届かない** |

- **200Hz までは目標周期をほぼ完全に維持できる。**
- 500Hz は平均 2.053ms（目標比 +2.7%）で回るが、p99 が 4.6ms まで伸びる。
- 1000Hz は平均 1.662ms で、そもそも目標に届かない。次項の I/O 時間が理由。

### 1.4 1 周期あたりの I/O 内訳

| 処理 | 平均 | 中央 | 最大 |
|---|---|---|---|
| 送信（CAN フレーム 1 本 = シリアル 13 バイト） | 0.599 | 0.598 | 2.154 |
| 受信（フィードバック 1 本の取り込み） | 1.160 | 1.166 | 1.484 |
| **合計** | **約 1.76** | | |

**I/O だけで約 1.8ms 必要**なので、5ms 周期（200Hz）に対しては 36% の占有で余裕があるが、
1ms 周期（1kHz）は物理的に不可能。これは **USB-CAN アダプタと CAN 往復の時間であり、
C# か Python かとは無関係**。

### 1.5 測定環境についての注意

**この測定は macOS 上のものです。** 研究室の実験を Windows で行う場合、次の理由で
再測定が必要です。

- Windows の既定タイマ分解能は約 15.6ms で、`Thread.Sleep` の挙動が macOS と大きく異なる
  （`timeBeginPeriod` の呼び出しが要る可能性がある）
- `System.IO.Ports` の実装が OS ごとに別物（Windows は Win32 API、Unix は termios）

ただし **スピン待ちは OS のタイマに依存しない**（`Stopwatch` = 高分解能カウンタを直接見る）ため、
Windows でも同等の精度が出る見込みです。

---

## 2. 実行環境【必須】

| 項目 | 内容 |
|---|---|
| 言語 | C# 14 |
| フレームワーク | .NET 10.0.10（SDK 10.0.302、LTS） |
| ターゲット | `net10.0`、`Nullable` / `ImplicitUsings` ともに有効 |
| OS | macOS 15.7.7（Apple Silicon, arm64, 8 論理コア） |
| 外部ライブラリ | **`System.IO.Ports` 10.0.10 のみ** |
| CAN 通信の実装 | **自前実装**（後述） |
| アダプタの扱い | **仮想 COM ポート（シリアルポート）として直接叩く。専用 DLL は使っていない** |
| ポート設定 | 2,000,000 bps / 8bit / パリティなし / ストップビット 1 / フロー制御なし |
| デバイス | CH340（VID 0x1a86 / PID 0x7523）→ `/dev/cu.usbserial-120` |

### CAN 通信をどう実装したか

Python 版は `python-can` の `seeedstudio` バックエンドが USB-CAN Analyzer を扱っていましたが、
**.NET には同等のライブラリが存在しません。** そのため、アダプタのシリアルプロトコルを
自前で実装しました（`SeeedCanBus.cs`）。

```
初期化   AA 55 12 [速度] [フレーム種別] [フィルタ4B] [マスク4B] [動作モード] 01 00×4 [CRC]
送受信   AA [0xC0|拡張<<5|RTR<<4|DLC] [ID 2B(標準) リトルエンディアン] [データ] 55
状態応答 AA 55 [18バイト]
```

CRC は先頭 2 バイトを除く総和の下位 8bit です。

**この移植が正しいことは、Python 版が実際に生成するバイト列を採取して期待値にした
自動テスト 87 件で検証しています**（`dotnet test`、実機不要）。
初期化フレーム・使能/失能・速度指令・モード読み書き・フラッシュ保存・MIT フレーム・
フィードバック解釈のすべてが Python 版とバイト単位で一致します。

---

## 3. 制御内容【必須】

| 項目 | 内容 |
|---|---|
| 制御モード | **速度モード（3 / VELOCITY）** |
| 指令値 | 0.5 rad/s（約 3 rpm） |
| 継続時間 | 12.6 秒（= 1.0 回転ぶん） |
| 指令の送出 | 約 5ms ごとに速度指令フレームを送り続ける |
| 停止処理 | 速度 0 を 30ms 間隔で 10 回送出 → 失能 |

モータのフラッシュには既に速度モードが保存されていたため、モード変更は行っていません。

MIT モード（`MitCommand` / `MitMove`）も実装済みですが、**今回は実機で試していません。**

---

## 4. 結果【必須】

### 4.1 回転角度

| | Python 版（Windows, 8/6） | C# 版（macOS, 8/10） |
|---|---|---|
| 指令 | 0.5 rad/s × 1 回転 | 同じ |
| 実測 | 359.5〜359.6 度 | **358.5 度** |
| 目標との誤差 | −0.4〜−0.5 度（−0.13%） | **−1.5 度（−0.42%）** |
| 速度のばらつき | ほぼ無し | ほぼ無し |

### 4.2 誤差についての考察

**速度制御の誤差ではありません。** 2 秒ごとの位置は

```
t=2.0s −1.72 → 4.0s −0.72 → 6.0s +0.29 → 8.0s +1.28 → 10.0s +2.29 → 12.0s +3.29 [rad]
```

と 2 秒あたり 1.00 rad 一定で、実速度は 0.5008 rad/s（指令比 +0.16%）でした。

誤差の正体は**計測窓**です。回転量は「最初に受信したフィードバック」から
「最後に受信したフィードバック」までの差分を積算しているため、
① 使能してから最初のフィードバックが届くまで ② 最後のフィードバック以降の減速停止中、
の 2 区間が計上されません。位置データから逆算すると、今回欠けたのは約 70ms 相当でした
（Python 版は約 18ms 相当）。**Python 版と同じアルゴリズムであり、移植の誤りではありません。**

なお、この計測方法は両版とも数十 ms 分を取りこぼす作りになっています。
正確に測るなら、停止シーケンス中もフィードバックを積算する必要があります。

### 4.3 フィードバックの取得

**すべて問題なく取得できました。**

| 項目 | 取得値の例 |
|---|---|
| 位置 | −2.70 rad →（12 秒後）+3.29 rad、連続取得 |
| 速度 | 取得可（12bit、±30 rad/s レンジ） |
| トルク | 取得可（12bit、±10 N·m レンジ） |
| エラーコード | 0（正常）を維持 |
| ドライバ温度 / ロータ温度 | 28℃ / 27℃、走行中の上昇なし |

定周期ループでの受信取りこぼしも確認しました。**200Hz で 2000 サイクル送信して
応答 2000 件**（取りこぼし 0）。500Hz で 1500 件、1000Hz で 3000 件と、
どの周波数でも指令 1 本に対しフィードバック 1 本が確実に返っています。

このほか、バススキャン（CAN ID 1〜8 を順に叩いて応答を探す）で ID=4 のみを正しく検出、
パラメータ読み出し（0x7FF あて）で制御モード 3 を読み出せることも確認済みです。

---

## 5. つまずいた点と解決方法【あると良い】

### 5.1 `SerialPort.ReadByte()` が 1 回 1.16ms かかる（最大の落とし穴）

**症状**: 目標 200Hz（5ms）で回そうとしても、待ち方を何に変えても
**実周期が 16ms（≒62Hz）から下がらない**。1000Hz を狙っても 15.9ms。

**切り分け**: 素の `SerialPort` で「書き込み＋スピン待ち」だけのループは 5.000ms で
回ることを確認。差分は受信処理だけだった。そこで受信の内訳を計測したところ、

| 読み方 | 1 回あたり |
|---|---|
| `ReadByte()` を 1 バイトずつ | **1.156ms** |
| `Read(buffer, 0, n)` でまとめ読み | 0.290ms（13 バイト分） |

**原因**: 移植当初、受信パーサを Python 版と同じ「1 バイトずつ読んで解釈する」構造で
書いていた。CAN フレーム 1 本はシリアル 13 バイトなので、
**13 × 1.16ms ≒ 15ms** がまるまる 1 周期に乗っていた。
Python（pyserial）では 1 バイト読みが安いため顕在化しない問題で、
.NET の `SerialPort` に固有の落とし穴。

**解決**: 受信を「`BytesToRead` 分を一括で読んで内部バッファに貯め、
パーサはそのバッファから取る」方式に変更。

```csharp
// 受信は必ずまとめ読みしてバッファに貯め、パースはそこから行う
private int ReadByte(long deadline)
{
    if (_receiveHead < _receiveTail) return _receiveBuffer[_receiveHead++];

    int available = _port.BytesToRead;
    if (available > 0)
    {
        _receiveTail = _port.Read(_receiveBuffer, 0, Math.Min(available, _receiveBuffer.Length));
        _receiveHead = 0;
        ...
    }
}
```

**効果**: 受信 15.08ms → **1.16ms**、実周期 16.3ms → **5.000ms**。

### 5.2 `python-can` に相当するライブラリが .NET に無い

アダプタのシリアルプロトコルを自前実装した（§2 参照）。
正しさは Python 版から採取したバイト列との一致テスト 87 件で担保している。

### 5.3 Ctrl+C でプロセスが即死し、失能処理が走らない

C# は既定だと Ctrl+C で `finally` を通らずに終了する。Python 版と同じ安全性を保つため、
`Console.CancelKeyPress` を捕まえて減速停止 → 失能に回すようにした。

### 5.4 `Spin(speed: 0)` が無限ループになる

Python では所要時間の計算がゼロ除算で例外になるが、C# の `double` は無限大になり
**回り続けてしまう**。明示的に例外を投げるようにした。

### 5.5 macOS の 2Mbps は問題なかった

macOS の termios には Linux と違い `B2000000` の標準定数が無いため懸念していたが、
`SerialPort` で 2,000,000 bps を指定して正常に通信できた。

---

## 6. Python と比べての所感【あると良い】

### 書きやすさ

**Python の方が短く速く書ける。** 今回の移植でコード量はおよそ 2.5 倍になった
（Python 約 310 行 → C# 約 800 行、テストを除く）。型宣言、プロジェクト構成、
`csproj` の管理といった Python には無い手間がかかる。

一方で **C# は「壊れにくさ」で優る**。

- `null` になりうる箇所がコンパイル時に分かる（`Nullable` 有効）
- `ControlMode.Velocity` のような列挙型で、マジックナンバー 3 の取り違えが起きない
- IDE の補完とリファクタリングが確実に効く

倒立振子のように**状態量が増えて式が複雑になる**コードでは、この差は効いてくると思う。

### 速さ

**実行速度は今回の用途では差が出ない。** 律速は USB-CAN アダプタの往復（約 1.8ms/周期）で、
言語処理系の速度ではない。C# の計算が速くても、アダプタが待ってくれない。

ただし**リアルタイム性の制御手段は C# の方が揃っている**。

| | C# | Python |
|---|---|---|
| GC の制御 | `SustainedLowLatency` などで明示指定できる | 実質不可（`gc.disable()` 程度） |
| スレッド優先度 | 指定できる | OS 依存で扱いにくい |
| 高分解能タイマ | `Stopwatch`（今回 1ns 分解能） | `time.perf_counter()` で同等 |
| ヒープ確保の回避 | `Span`、事前確保、構造体で可能 | 難しい |

今回 200Hz × 2000 サイクルの測定で **GC 発生 0 回**を達成できたのは、
事前確保とレイテンシモード指定を明示的に行えたため。

### テストのしやすさ

**ここが一番大きな差だった。** CAN バスをインターフェースにして偽バスに差し替えることで、
**実機が無い状態で 87 件の検証を自動化**できた。移植中に「Python 版と同じバイト列が出ているか」を
何度でも確認できたのは C#（というより静的型付け＋テスト基盤）の恩恵が大きい。

---

## 7. ソースコードの要点【あると良い】

構成（`モータ制御プログラム一式_20260806/csharp/`）:

| ファイル | 役割 |
|---|---|
| `src/DamiaoCan/Motor.cs` | 使能/失能・状態取得・モード読み書き・速度制御・MIT 制御 |
| `src/DamiaoCan/SeeedCanBus.cs` | USB-CAN アダプタのシリアルプロトコル（自前実装） |
| `src/DamiaoCan/ICanBus.cs` | CAN バスの抽象。テストや別アダプタ用の差し替え口 |
| `src/DamiaoCan/MotorFeedback.cs` | 8 バイトフィードバックの解釈 |
| `src/DamiaoCan/MotorScaling.cs` | MIT フレームの値域と実数⇔整数の換算 |
| `src/DemoOneTurn/Program.cs` | 1 回転デモ |
| `tests/DamiaoCan.Tests/` | 実機不要の自動テスト 87 件 |

### 定周期ループの骨格（今回 200Hz を達成した形）

```csharp
long periodTicks = Stopwatch.Frequency / 200;        // 200Hz
long deadline = Stopwatch.GetTimestamp() + periodTicks;

for (int i = 0; i < cycles; i++)
{
    bus.Send(frame);                                  // 指令を送る
    if (bus.Receive(TimeSpan.Zero) is { } feedback)   // フィードバックを取り込む
        Update(feedback);

    // Thread.Sleep は使わない。Stopwatch を見ながらスピン待ちする
    while (Stopwatch.GetTimestamp() < deadline) Thread.SpinWait(20);

    deadline += periodTicks;
    if (Stopwatch.GetTimestamp() > deadline)          // 大きく遅れたら詰めずに刻み直す
        deadline = Stopwatch.GetTimestamp() + periodTicks;
}
```

要点は 3 つ。

1. **`Thread.Sleep` を周期生成に使わない**（§1.2 の通り最大 52ms に飛ぶ）
2. **ループ内でヒープを確保しない**（フレームとバッファは事前確保して使い回す）
3. **遅れたときに取り戻そうとして詰めない**（連続で短周期になり不安定化するため）

### 安全対策

- 例外・Ctrl+C・正常終了のいずれでも**必ず失能**する（`try/finally` ＋ `IDisposable`）
- `Spin` / `MitMove` は `CancellationToken` で中断でき、中断時も減速停止 → 失能を通る
- 上記の挙動はテストで検証済み（例外発生時に失能フレームが最後に送られることを確認）

---

## 8. 相談事項への回答：倒立制御を C# と Python のどちらで実装するか

### 判断材料「200Hz を安定して回せるか」について

**C# は回せます。実測で平均 5.000ms、標準偏差 3μs、最大偏差 ±44μs。**
200Hz に対しては十分すぎる精度で、余力もあります（500Hz まで実用範囲）。

ただし、**この判断材料だけでは C# を選ぶ根拠として弱い**と考えます。理由は 2 つあります。

**1. 律速はアダプタであって言語ではない。**
1 周期の I/O に約 1.8ms かかっており、これは USB-CAN アダプタと CAN 往復の物理時間です。
Python でも同じ 1.8ms がかかり、残り 3.2ms を Python で使い切ることは考えにくい。
**Python でも 200Hz は出る可能性が高い**と思います（未測定です）。

**2. C# にも 200Hz を殺す落とし穴があった。**
§5.1 の通り、素直に書いたら 62Hz しか出ませんでした。
「言語が速いから大丈夫」ではなく、**どちらの言語でも実測しないと分からない**というのが実感です。

### メンバーBの意見

**C# を推します。ただし理由は速度ではありません。**

1. **実機なしで検証できる基盤がすでにできている。**
   87 件の自動テストがあり、CAN バスを差し替えられる構造になっています。
   倒立制御では状態推定・LQR ゲイン・スイングアップと検証したいロジックが増えます。
   モータを回さずにロジックを詰められる価値は、開発期間を考えると大きいと思います。

2. **状態量が増えたときに壊れにくい。**
   倒立振子はアーム角・振子角・それぞれの角速度と、扱う値が増えます。
   単位や符号の取り違えが起きやすい領域で、静的型付けと列挙型が効きます。

3. **研究室の方針が C# であり、資産が引き継がれる。**
   今回作った通信層はそのまま流用できます。

### 一方で、Python を選ぶ合理性もあります

- **試行錯誤の速さ**。ゲイン調整のように「値を変えて即試す」作業は Python が有利です。
- **数値計算ライブラリ**。状態推定や LQR ゲインの設計で NumPy / SciPy / control を使うなら、
  Python の方が圧倒的に楽です。C# には同等の成熟したライブラリがありません。
- **8/6 の動作実績がある**（ただし C# も 8/10 に実機で 1 回転を確認済み）。

### 提案：役割を分けるのが現実的では

- **ゲイン設計・シミュレーション・モデル同定は Python**（NumPy / SciPy / control を使う）
- **実機の制御ループは C#**（求めた最適ゲインを定数として渡す）

制御ゲインは実行時に計算するものではないので、この分け方なら両方の利点を取れます。

### 決める前にやるべきこと

**Python 側でも同じ 200Hz のジッタ測定を行うことを提案します。** 今回 C# で使った測定手順は
そのまま Python に移せます（送信 → 受信 → `perf_counter` でスピン待ち、全周期の間隔を記録）。
30 分程度で終わり、**憶測でなく実測で比較できます。**
C# が 5.000ms / σ3μs という数字を出しているので、比較の基準は明確です。

---

## 付録：未実施・未確認の事項

正確を期すため、**今回確認できていないこと**を明記します。

- **Windows での測定**（今回はすべて macOS）。研究室が Windows なら再測定が必要
- **MIT モードの実機動作**。実装とテストは済んでいるが、実機では試していない
- **モータを実際に回しながらの 200Hz 測定**。ジッタ測定は失能状態（安全のため）で実施
- **長時間運転での温度上昇・安定性**。今回の連続運転は最長 12.6 秒
- **Python 版の 200Hz ジッタ**。比較対象として未測定

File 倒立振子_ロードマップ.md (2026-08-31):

# 回転型倒立振子（Furuta）製作ロードマップ

- **アクチュエータ**: DM-J4310-2EC V1.1（減速比 10:1、MIT モードによるトルク制御）
- **振子部**: Quanser **QUBE-Servo 2 回転振子モジュール一式**（磁石台座付き、入手済み）
- **期間**: 2026/08/10（月）〜 2026/08/27（木）、月・水・木の週3回 × 3週 = 全9回
- **目標**: スイングアップ付き回転型倒立振子の完成

**Day 1（8/10）完了済み。** MIT モード移行、レジスタ照合、純粋トルク指令 API、逆駆動テスト、静止摩擦の実測。

---

## 全体方針

平衡制御は **LQR による状態フィードバック**。極配置は重みの物理的意味が不明瞭で試行錯誤になり、
PID カスケードは4状態を2ループに分割するためチューニングが困難、MPC は初号機には過剰。

制御ループは **PC 側（C#）に置く**。速度モードで既に動作している資産を活かす。
ESP32 は E8P エンコーダを読んで USB シリアルに垂れ流すだけの役割に限定する。

---

## 中心的な制約：摩擦が必要トルクの10倍ある

Day 1 に実測した静止摩擦は **τ_c = 0.147 N·m**（定格 3 N·m の約5%。10:1 遊星ギヤとして正常な値）。

一方、QUBE-Servo 2 の素の寸法（アーム 85 mm / 95 g、振子 129 mm / 24 g）で
平衡制御に必要なアームトルクは **約 0.014 N·m** しかない。**約10倍の差。**

QUBE 本体のモータは最大 0.02〜0.03 N·m 級であり、**我々の摩擦だけで QUBE のモータの
全トルクの5倍以上ある**。QUBE はダイレクトドライブ前提の設計だからこれで成立している。

摩擦補償で埋められるのは良くて7〜9割なので、**機構側で必要トルクを上げないと立たない。**

### 対策：モジュールは分解せず「足す」だけ

必要トルクは概ね **τ ∝ 振子質量 × アーム長**。この2つだけを外付けで増やす。

| 改造 | 内容 | 効果 |
|---|---|---|
| **A. アーム延長バー** | DM-J4310 出力軸と QUBE アームハブの間にアルミバーを挟む。実効アーム長 85 → **300 mm** | モジュール無改造 |
| **B. 振子先端に錘** | 既存ロッド先端に **150 g** のカラーを追加（24 g → 174 g） | ネジ止めのみ、可逆 |

→ 必要トルク **約 0.154 N·m**。τ_c と同オーダーになり、摩擦補償と併せて実用域。

> 錘を増やすと不安定極は 10.7 → 9.0 rad/s（時定数 0.094 → 0.11 秒）とわずかに遅くなる。
> それでも短い振子なので速い部類。**制御周期は 500 Hz を狙う。**

> **数度のリミットサイクルが残ることは織り込む。** 減速機付きモータで Furuta を作る以上
> これは避けられず、摩擦補償とディザで緩和する。

---

## ハードウェア仕様

### 振子角センサ（QUBE 内蔵）

**US Digital E8P-512-118** シングルエンド光学エンコーダ。**4ピン（CON-MIC4）**。

| ピン | 信号 |
|---|---|
| 1 | +5 V |
| 2 | A 相 |
| 3 | GND |
| 4 | B 相 |

- 電源 **5.0 V（4.5〜5.5 V）**。3.3 V では動作しない
- 512 ライン → 4逓倍で **2048 カウント/回転 = 0.176°/カウント**
- **インデックス（Z相）なし** → 絶対角は取れない。振子を垂らした静止位置（α=π）でゼロ点を取る

⚠️ **ESP32 は 3.3 V I/O。A/B を直結すると壊れる。** レベルシフタか抵抗分圧（10k/20k）を必ず入れる。
⚠️ ESP32 の **PCNT（パルスカウンタ）**でハードウェア直交デコードする。取りこぼしが原理的に起きない。

### T_MAX を 1.0 N·m に下げる（重要）

現在 `T_MAX = 10 N·m` を 12bit で割るので **1 LSB = 4.9 mN·m**。
改造後の制御トルク 154 mN·m でも31段階しかなく、粗すぎる。

**`T_MAX`（RID 23）を 1.0 N·m に下げると分解能が 0.49 mN·m と10倍細かくなる。**
この振子には ±1.0 N·m で十分。

- `MotorScaling.TorqueMax` を同時に書き換える（**指令とフィードバック両方の解釈が変わる**）
- 変更後は必ずトルク校正をやり直す
- 変更は `SetControlMode` ツールと同じパラメータ書き込み機構で可能

---

## 発注・調達リスト

QUBE モジュールで軸受・エンコーダ・振子が揃ったため、当初リストから大幅に減った。

| 品目 | 用途 | 備考 |
|---|---|---|
| ESP32 ×1 | E8P 読み取り | PCNT が使えるもの |
| **レベルシフタ（5V↔3.3V）** | E8P → ESP32 | 双方向でなくてよい。抵抗分圧でも可 |
| **5V 電源** | E8P 用 | USB から取ってもよい |
| CON-MIC4 対応ケーブル | E8P 接続 | 現物のコネクタを確認してから |
| **アルミ板 t5（アーム延長バー用）** | 改造A | 300 mm。たわむと制御性能が直接落ちる |
| **DM-J4310 出力軸→バーのアダプタ** | 改造A | 3Dプリント可 |
| **錘（50 g / 100 g / 150 g）** | 改造B | 段階的に試すため複数 |
| M3/M4 ネジ・スペーサ類 | | |
| **非常停止スイッチ / ブレーカ** | 安全 | **必須** |

**不要になったもの**: AS5600、深溝玉軸受、φ6 アルミ丸棒、カーボンパイプ

---

# Week 1

## Day 1（月 8/10）✅ 完了

- [x] MIT モードへ変更＋フラッシュ保存、電源再投入して定着確認
- [x] `P_MAX` / `V_MAX` / `T_MAX` の実レジスタ値を照合 → 12.5 / 30.0 / 10.0 で一致。減速比 10:1
- [x] `Motor.TorqueCommand(torqueNm)` を追加（`kp=kd=0` を保証、単体テスト済み）
- [x] 逆駆動テスト（A/B 判定）→ 合格。寄生トルクなし
- [x] 静止摩擦の実測 → **τ_c = 0.147 N·m**

## Day 2（水 8/12）トルク校正とループ品質

- [x] **動摩擦・粘性の実測** → **τ_coulomb = 0.126 N·m / b = 0.027 N·m·s/rad**
      （正転 0.109 / 逆転 0.143 と非対称。摩擦補償は正逆で別係数を持たせること）
- [x] **制御周期の決定** → **300 Hz**（下表）。USB-CAN の往復遅延が約 2.3 ms で 436 Hz が上限
- [x] **`T_MAX` を 2.0 N·m に変更**し、`MotorScaling` を同期。既知の摩擦を測り直して整合を確認
- [x] `Motor.VerifyScaling()` を追加（トルクを出す前に必ず呼ぶ安全網）
- [ ] **トルクスケールの実測校正**（`TorqueCalibration --mode sweep`）← 実物の腕＋錘が必要
- [ ] **重力補償デモ**（`TorqueCalibration --mode float`）← 同上

### 実測した制御周期（2026/08/12、素のモータ、12秒間）

| 目標 | 実測平均 | 標準偏差 | 95%点 | 最大 | 取りこぼし |
|---|---|---|---|---|---|
| 200 Hz | 5.000 ms | 0.820 | 5.92 | 21.7 | 0% |
| **300 Hz ←採用** | **3.333 ms** | **0.563** | **3.75** | 21.8 | 0% |
| 400 Hz | 2.500 ms | 0.851 | 3.61 | 33.1 | 0% |
| 500 Hz | 2.294 ms ✗ | 1.158 | 3.52 | 38.3 | 0% |

**Day 3 のシミュレーションに入れる値**: 制御周期 3.33 ms、常用遅延 約 5 ms、
まれに 22 ms の外れ値。振子の時定数 約 100 ms に対して常用 5%、最悪 20%。

**完了条件**: 重力補償が成立。→ 実測値は上表のとおり揃っている。

## Day 3（木 8/13）シミュレーション環境 ✅ 完了（8/12 に前倒し実施）

- [x] SymPy で Furuta の運動方程式を導出 → [`../model/furuta_model.py`](../model/furuta_model.py)
- [x] `A = ∂f/∂x`, `B = ∂f/∂u` を平衡点で数値評価。**不安定極 13.0 rad/s（時定数 77 ms）**、可制御性ランク 4/4
- [x] LQR ゲイン計算（Bryson の法則）
- [x] 定常カルマンフィルタのゲイン設計
- [x] **実測の遅延・ジッタ・量子化・非対称クーロン摩擦を入れた非線形閉ループ検証**
- [x] 摩擦補償 `τ += τ_c·tanh(θ̇/ε)` を組み込み
- [x] 感度解析（摩擦補償の効き、アーム慣性 J_r）
- [x] ゲインを C# 定数として出力 → [`../model/FurutaGains.cs`](../model/FurutaGains.cs)

### 結果

| ケース | 結果 | リミットサイクル | 最大トルク |
|---|---|---|---|
| 初期傾き 3° | 成立 | 0.97° | 0.65 N·m |
| 初期傾き 6° | 成立 | 0.99° | 1.31 N·m |
| 初期傾き 10° | 成立 | 1.00° | 2.00 N·m（飽和） |
| 外乱 0.15 N·m × 30 ms | 成立 | 1.02° | 0.20 N·m |

**感度**: 摩擦補償の効きを 0〜1.1 倍に振っても成立（補償なしで 1.62°、完全補償で 0.91°）。
アーム慣性 J_r を 0.5〜3 倍に振っても成立。**推定値の誤差に対して頑健。**

> ⚠️ **シミュレーションのクーロン摩擦は tanh 近似**で、真の固着（速度ゼロでの停留）は
> 表現できていない。実機の摩擦はこれより厳しいはず。**摩擦補償は外さないこと。**

> ⚠️ アームが ±8° 程度をゆっくり往復する（摩擦由来の遅い振動）。
> 振子は 1° 以内に収まっているので許容だが、Day 7 の積分項で改善を試みる。

**完了条件**: 達成。

> **摩擦補償を最初から入れる理由**: 平衡点近傍では必要な制御トルクが定義上ゼロに近づくため、
> **どれだけ設計をスケールアップしても必ず摩擦の不感帯に入る**。摩擦を「上回る」ことは
> 原理的にできない。したがって摩擦補償は「余裕があればやる」ではなく設計の前提。

---

# Week 2

## Day 4（月 8/17）機構改造とエンコーダ配線

- [ ] **アーム延長バーの製作**（改造A）。DM 出力軸アダプタ＋300 mm バー。剛性を確保する
- [ ] QUBE モジュールを延長バー先端に固定
- [ ] **振子先端に錘を追加**（改造B）。**50 g から始めて手で回し、軸受の渋りが出ないか確認**
- [ ] E8P の 4ピンから配線を引き出し、レベルシフタ経由で ESP32 へ
- [ ] ESP32 の PCNT で直交デコード、USB シリアルへ垂れ流すファーム
- [ ] **スリップリングの有無を確認**（スイングアップで全周回転するため）

**完了条件**: 振子が滑らかに全周回転し、角度が正しく読める。
配線が絡まない。ガタつきはここで直す（後工程では直せない）。

## Day 5（水 8/19）パラメータ同定と統合

- [ ] アーム長・振子長・振子質量を**実測**（カタログ値を信用しない）
- [ ] 振子を下向きに吊るして微小振動 → 周期 T から `J₁_hat = m₁·g·l₁·(T/2π)²`
- [ ] 同じ自由振動の振幅の対数減衰から `b₁`
- [ ] 同定値をモデルに反映して LQR ゲイン再計算
- [ ] CAN ループ ＋ シリアル読み取り ＋ オブザーバ ＋ LQR を1本の固定周期ループに統合

**完了条件**: 全状態がリアルタイムに正しく表示される。トルク指令はまだ 0 のまま。

## Day 6（木 8/20）**実機で立てる**

1. [ ] **振子を手で持ったまま**制御を有効化し、傾けた向きにアームが正しく押すか確認 ← 符号ミスをここで殺す
2. [ ] トルクリミットを本来の 1/3 に絞って手を離す
3. [ ] 立ったらリミットを戻し、Q/R を調整（振子が落ちそう→α の重みを上げる／アームが暴れる→θ か R を上げる）

**完了条件**: 手で上向きにしてやれば自立する。

---

# Week 3

## Day 7（月 8/24）安定性の作り込み

- [ ] 摩擦補償の係数 τ_c と平滑化幅 ε を実機で追い込む（実装自体は Day 3 で済んでいる）
- [ ] **リミットサイクルが残るならディザを投入**（この構成では最も効く可能性が高い）
- [ ] **錘を 50 g → 100 g → 150 g と増やして安定性の変化を見る**（軸受の渋りに注意）
- [ ] 振子零点の精密校正（1°のズレがアームの定常ドリフトになる）
- [ ] θ の積分を5番目の状態として加えた拡大系 LQR でドリフト除去
- [ ] 外乱応答（指で突く）の確認

## Day 8（水 8/26）スイングアップ

- [ ] エネルギー整形則の実装
  - `E = ½·J₁_hat·α̇² + m₁·g·l₁·(cos α − 1)`（上向き静止で 0）
  - `u_accel = k·(E − 0)·sign(α̇·cos α)` ※飽和付き、符号はシミュレーションで確認
- [ ] 切り替え条件: **`|α| < 20°` かつ `|α̇|` が閾値以下**（角度だけで切り替えると吹き飛ぶ）
- [ ] 切り替え時にオブザーバ状態が連続であることを確認

## Day 9（木 8/27）予備日・仕上げ

- [ ] ログ・可視化、デモ用の起動手順整備
- [ ] **または Day 6〜8 の遅れの吸収**

---

# リスクと調整弁

**この構成の最大のリスクは摩擦。** 必要トルクと摩擦が同オーダーなので、
当初計画（振子 250 g / アーム 200 mm の自作）より余裕が小さい。
Day 3 のシミュレーションで摩擦を入れて立たない場合は、**Day 4 の時点で錘をさらに増やす**か、
アーム延長バーをより長くする（300 → 400 mm）ことで対応する。

**Day 6 が一発で通らない前提で組んである。** 通らなければ Day 7 を丸ごとデバッグに使い、
スイングアップを Day 8→9 にずらせば間に合う。

**それでも遅れた場合に切るのはスイングアップ。**
「手で上向きにセットすれば立って、突いても倒れない」までできていれば倒立振子としては完成。
**平衡制御を犠牲にしてスイングアップを優先することは絶対にしない。**

**Day 3 のシミュレーションを飛ばさない。** 実機デバッグ時に
「制御則が悪いのか実装が悪いのか」を切り分ける唯一の基準になる。

---

# 技術メモ

## DM モータ CAN プロトコル

**制御モードは送信 CAN ID のオフセットで決まる**

| モード | 送信 CAN ID |
|---|---|
| MIT | `0x000 + ID` |
| 位置速度 | `0x100 + ID` |
| 速度 | `0x200 + ID` |
| 力位混合 | `0x300 + ID` |

ただしファームによっては `CTRL_MODE` レジスタも合わせないと無反応
（1=MIT / 2=位置速度 / 3=速度 / 4=力位混合）。**現在は MIT(1) でフラッシュ保存済み。**

**特殊コマンド**（8バイト。モータIDあてに送る。`0x104` や `0x204` では受け付けられない）

| コマンド | データ |
|---|---|
| Enable | `FF FF FF FF FF FF FF FC` |
| Disable | `FF FF FF FF FF FF FF FD` |
| ゼロ点設定 | `FF FF FF FF FF FF FF FE` |
| エラークリア | `FF FF FF FF FF FF FF FB` |

**エラーコード**: 0=正常, 1=使能中, 8=過電圧, 9=低電圧, A=過電流, B=MOS過温, C=コイル過温, D=通信喪失, E=過負荷

**主なレジスタ（RID）**: 7=MST_ID, 8=CAN_ID, 9=TIMEOUT, 10=CTRL_MODE,
20=減速比, 21=P_MAX, 22=V_MAX, **23=T_MAX**

`Motor.ReadParameterSingle(RegisterId.TorqueMax)` で CAN 経由で直接読める。
公式上位機（達妙調試助手）は入手できていないが、これで代替できる。

## 状態推定（最大の技術的難所）

4状態のうち角速度2つは直接測れない。素朴な差分は量子化ノイズを増幅し、
それを潰すために LPF を強くかけると位相遅れで発振する。**失敗の主原因はここ。**

→ **線形モデルベースの定常カルマンフィルタ**を使う。観測は θ と α の2つ、モデルは `A`, `B` を流用。
モデルが速度を予測するため位相遅れが原理的に小さい。定常ゲインを事前計算すれば実行時は行列積2回。

簡易に各角度2状態のカルマンで済ませる場合も、**LPF のカットオフは振子の固有振動数（約 1.4 Hz）の
10倍以上**を確保する。

## 安全

- ホスト側ウォッチドッグ（一定時間指令が来なければトルク0）
- 角度リミット
- 温度監視（フィードバックの MOS・ロータ温度）
- エラーコードのパース（エラーで勝手に disable される）
- 例外・Ctrl+C・正常終了のいずれでも必ず Disable を送る（`try/finally`）

## 動かないときにまず疑う順序

1. **24V 電源が入っているか**（LED 赤＝失能 / 緑＝使能）
2. 送信 CAN ID のオフセット（MIT は `0x000+ID`）
3. `CTRL_MODE` がフラッシュに保存されているか
4. `MotorScaling` の定数とレジスタ実値の一致（**T_MAX 変更後は特に**）

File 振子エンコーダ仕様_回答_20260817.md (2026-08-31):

# 振子エンコーダ 仕様検討への回答

2026/08/17 メンバーB → メンバーA

いただいた3点について、シミュレーションで数字を出しました。結論から書くと
**分解能は現物で十分、ジッタは思ったより緩い制約、効くのは遅延**です。

以下の数値はすべて、本日実測したアーム慣性 `J_r = 2.13e-3 kg·m²` を反映した
モデルに基づいています。この値は従来の概算の 5.3 倍で、制御権限が 5 分の 1 に
落ちているため、8/14 以前の検討結果からは条件が変わっています。

---

## ① 分解能：E8T-512（0.176°/count）で十分です

α の分解能だけを振って、倒立時のリミットサイクル振幅を見ました。

| 分解能 | 1カウント | リミットサイクル |
|---|---|---|
| 理想（量子化なし） | — | 2.07° |
| 8192 count/rev | 0.044° | 2.04° |
| 4096 count/rev | 0.088° | 2.02° |
| **2048 count/rev ← 現物** | **0.176°** | **2.07°** |
| 1024 count/rev | 0.352° | 2.14° |
| 512 count/rev | 0.703° | 2.12° |
| 256 count/rev | 1.406° | 2.47° |

理想と現物で差がありません。**8倍粗い 256 count/rev でも成立します。**

### なぜ効かないか

律速しているのは分解能ではなく**クーロン摩擦 0.126 N·m** です。

α の 1 LSB がトルク指令に与える揺れは

```
K[1] × LSB = 12.81 × 3.07e-3 = 0.039 N·m
```

で、クーロン摩擦の 3 分の 1 以下。さらにオブザーバが平滑化します。
測定を細かくしても、摩擦由来の 2° 程度のリミットサイクルは減りません。

**→ E8T-512 のままで問題なし。より細かいエンコーダに投資する意味はありません。**

---

## ② 送信周期：等間隔は必須条件ではありません。効くのは遅延です

### 前提の訂正

「タイミングジッタが量子化誤差の7倍」という数字は、私が **モータ側の CAN
フィードバック** について出したものです。そこでの結論は「ジッタをゼロにせよ」
ではなく「**オブザーバ設計時に観測雑音へジッタ分を計上せよ**」でした。

実際、観測雑音を量子化誤差だけで見積もっていたために、オブザーバゲイン L が
2.4e5 まで暴れて全ケース転倒したのが本日の詰まりどころです。ジッタ分を
入れたら L は 6.2e3 に下がり、全ケース成立しました。

### ジッタと遅延は効き方が違う

- **ジッタ（標本化時刻のばらつき）** … 観測雑音として現れる。カルマンフィルタが吸収する
- **遅延（純粋な時間遅れ）** … 位相遅れとして現れる。**吸収できない**

数値で確認しました。オブザーバは公称設計のまま固定しています。

**ジッタ耐性**

| σ_t | 結果 | リミットサイクル |
|---|---|---|
| 0.5 ms | 成立 | 2.09° |
| 1.0 ms | 成立 | 2.24° |
| 2.0 ms | 成立 | 1.95° |
| 5.0 ms | 成立 | 2.66° |

**遅延耐性**

| 伝送遅延 | 結果 |
|---|---|
| 20 ms | 成立 |
| 30 ms | 成立 |
| **40 ms** | **成立（限界）** |
| 50 ms | ★転倒（0.25 s） |
| 60 ms 以上 | ★転倒（0.10 s） |

**破綻点は 40〜50 ms の間**で、不安定極の時定数 90 ms の約半分です。
ジッタは 5 ms でも平気ですが、遅延は 50 ms で落ちます。

### 提案する仕様

| 項目 | 値 | 根拠 |
|---|---|---|
| 送信レート | **1 kHz** | 制御周期 3.33 ms に対し常に 1 ms 以内の新しい値がある状態にする |
| 遅延 | **10 ms 以下** | 破綻点 40〜50 ms に対し 4〜5 倍の余裕 |
| ジッタ | 2 ms 以下（努力目標） | 守れなくても致命傷にならない |
| タイムスタンプ | **付ける** | 下記参照 |
| サンプリング | **ハードウェアタイマ割り込み** | `loop()` 内だとタイムスタンプが実態を表さない |

300 Hz に同期させる必要はありません。同期機構のほうが高くつきます。

### タイムスタンプを付ける理由

1. PC 側で `α̇ × 経過時間` の外挿ができ、**受信側ジッタの影響を原理的に消せる**
2. 遅延とジッタを**推測ではなく実測**できる。これがオブザーバ設計の入力そのもので、
   今日詰まった原因がまさにここ
3. サンプル落ちと通信途絶をウォッチドッグで検出できる

コストは 4 バイトです。

なお**マイコンと PC の時計は同期しません**。タイムスタンプは相対間隔と鮮度の
判定にのみ使い、絶対時刻を合わせようとしないでください。

### 帯域

1 kHz × 13 バイト = **13 kB/s**。

- ネイティブ USB CDC … 余裕（~1 MB/s）
- UART ブリッジ 115200 baud … **11.5 kB/s で足りません**

921600 baud 以上か、ネイティブ USB を使ってください。

---

## ③ 単位：生カウントで送ってください

メンバーAさんの見立てのとおりです。理由を挙げます。

1. **整数で厳密。** 丸めも浮動小数の書式も入りません。度で送ると 0.176° を
   表すのに小数3桁が必要になります

2. **ゼロ点は PC が持つべき。** α=π のゼロは「垂らして静止させる」校正で決まり、
   毎回取り直す可能性があります。マイコンが度で出すと、自分が持っていない
   ゼロ点を暗黙に主張することになります。E8T にはインデックス（Z相）が無いので
   なおさらです

3. **多回転に耐える。** スイングアップ中に振子は何回転もします。
   **int32 の累積カウント**で送ってください（**剰余は取らない**）。
   2048 count/rev なら int32 で ±100万回転あり、実質ラップしません。
   剰余で送ると PC 側でアンラップ処理が必要になり、故障モードが1つ増えます。
   モータ側の 16bit エンコーダで `Motor.UnwrapDelta()` を書く羽目になったのと
   同じ話で、繰り返す必要はありません

4. **CPR が変わっても PC 側の定数1個**で済みます

5. **切り分けができる。** 振子をちょうど1回転させて 2048 が出るか確認できます。
   1024 しか出なければ4逓倍が2逓倍になっていると即座に分かります

### フレーム案（リトルエンディアン、13 バイト）

| フィールド | 型 | 用途 |
|---|---|---|
| sync | uint16 = 0xA5A5 | 同期 |
| seq | uint16 | 連番。欠落検出 |
| t_us | uint32 | マイコン側マイクロ秒 |
| count | int32 | 累積カウント（4逓倍・符号付き） |
| crc8 | uint8 | 化け検出 |

立ち上げ時だけテキスト出力に切り替えられるフラグがあると楽だと思います。

---

## 補足

### STM32G474RE なら TIM2 か TIM5 を使ってください

どちらも **32bit カウンタ**のエンコーダモードを持ちます。ハードウェアが
累積カウントをそのまま保持するので、③ の「int32 累積」という要件が
**オーバーフロー処理なしで自動的に満たせます**。

ESP32 の PCNT は 16bit でソフト側のオーバーフロー処理が要るため、
STM32 に移ったことで条件が良くなっています。TI12 両エッジで4逓倍です。

### レベル変換の確認

E8T は 5V シングルエンド出力です。G474 の該当ピンが 5V トレラント（FT）で
あればレベルシフタを省ける可能性があります。データシートでピンごとに
確認してください。判断がつかなければレベルシフタを入れたままで構いません。

### CLAUDE.md の記述が古い

振子エンコーダ側のマイコンを ESP32 + PCNT と書いてありますが、実際は
STM32G474RE です。こちらで更新しておきます。

---

## まとめ

| 論点 | 結論 |
|---|---|
| 分解能 | E8T-512（0.176°）で十分。8倍粗くても成立。変更不要 |
| 送信レート | 1 kHz。300 Hz への同期は不要 |
| 遅延 | **10 ms 以下**。これが唯一の厳しい要件（破綻点 40〜50 ms） |
| ジッタ | 2 ms 以下が望ましいが、5 ms でも成立する |
| タイムスタンプ | **付ける**。実測値がオブザーバ設計の入力になる |
| 単位 | **生カウント（int32 累積、剰余を取らない）** |
| ペリフェラル | TIM2 または TIM5（32bit エンコーダモード） |

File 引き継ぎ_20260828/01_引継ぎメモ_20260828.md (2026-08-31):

# 探究：回転型倒立振子プロジェクト 引継ぎメモ

**最終更新**：2026年8月28日（金）
**作業日**：8/24（月）〜8/28（金）を実施。メンバーAのPCで単独作業（8/26夜のみメンバーBが代理で作業）
**このファイルは`8月28日分/`にある（8/27までは`8月27日分/`にあった）**
**発表**：9月16日（9月はポスター制作に充てるため、実質の作業は8月中）

**★8/28終了時点の状態**：**調整完了・撮影完了。トルク上限1.0で確定。** 成功率は上限0.8で82.8%（29回）、1.5で85.7%（28回）、1.0で6回中5回。**倒立保持は最長61.6秒を確認。** 8/31（月）は予備日。

**★次に作業する人がまず読む場所**：§7の「8/28（金）の作業結果」。実行コマンド・確定した設定値・持ち越した課題がそこにまとまっている。
コードのスナップショットは `8月28日分/動作確認済みコード_20260828/`（壊したらここに戻す）。

**★COMポートが8/28に変わった：COM4=振子エンコーダ、COM8=モータのCAN変換。**

---

## 0.【最優先で読む】現在地のサマリー

- テーマは**回転型倒立振子（Furuta pendulum）で確定**。8/11に一度「モータの摩擦が大きすぎて成立しない」と判断したが、8/12にメンバーBがその判断の誤りを特定し、**素の寸法（QUBEモジュールそのまま、アーム延長・錘なし）で成立する見込み**が立っている
- 保険案（付け替え式アタッチメントによる力覚提示デモ）は、計画書のリスク対策欄に数行残してあるのみ。現状は倒立振子1本で進めている
- **8/21、TIM1ハードウェアエンコーダモードへの移行と、モータ稼働時のノイズ耐性の実測が完了。** 8/20の先生の指摘（ソフト割り込みだと稼働時にノイズ誤動作の恐れ）に対し、**この構成では誤カウントが発生しないことを実測で確認**（詳細は§4 8/21）
- **8/21、C#からモータを動かせることを確認。** .NET SDK 10.0を導入し、メンバーBの`DamiaoCan`ライブラリでMIT位置制御の往復動作に成功
- **8/14に、メンバーBがモータのフィードバックだけで振子の固有振動数を実測**し、モデルの予測と3%以内で一致することを確認
- **8/17にメンバーBがアームの慣性モーメントを実機測定**（J = 2.13×10⁻³ kg·m²）
- **8/21、モータの固定・かさ上げも解決**（電源の上に固定。新規の治具設計は不要になった）
- **8/21、C#側の受信実装が完成。** 振子角とアーム角を同時に受信し、オブザーバ・LQRの計算まで通った（`PendulumTelemetry`）。発散せず物理的に妥当な数値が出るところまで到達
- **8/21、先生のご指摘（USB-シリアルの遅延）への対応と効果測定まで完了。** `timeBeginPeriod(1)`で平均約600Hz・13ms超0回（34,883回中）を実測
- **8/21、u_totalの飽和処理を実装・実機確認済み**（±2.0 N·mで頭打ち）
- **8/21、実測でL_r＝113〜114mm、Ø4ピン穴の角度＝30°を確定**
- **★体制変更：8/24〜28はメンバーBが集中講義で不在（平日5日、2〜4限）。以降はメンバーAのPCで単独開発する方針。** メンバーBのリポジトリ全体を8/21に共有済み（`8月21日分/メンバーBリポジトリ_20260821/`）
- **8/24、座標系の符号の方針が確定。** メンバーBの回答は「言葉での照合は決着しない。実測で決めろ」。**(θ,α,u)を全部同時に反転してもA・Bは一致する対称性がある**ため、重要なのは向きの呼び方ではなく**3者が互いに整合しているか**。実測ツール`src/SignCalibration/`を新規作成
- **★8/24、測定1完了：`s_theta = +1`（確定）。** このプロジェクトで初めてモータに非ゼロトルクを送った操作
- **★8/26、測定2完了：`s_alpha = +1`（確定）。** これで符号は両方決着（`s_theta=+1`、`s_alpha=+1`）。組み立て直後は摩擦が減っており、測定1のパルス時間を300ms→150msに短縮して再測定した
- **8/24〜25、3Dプリンタで gauge / spacer / rail×2 まで完了。プリンタは Markforged Onyx One**（材料Onyx、PLA機ではない）。gauge実測で寸法の癖は−0.10mmと判明し、嵌合は問題なし
- **★8/25、最後の部品`base`の印刷が完了。4部品すべて刷り上がった**（ピン穴を有効化するとSTL生成が落ちるバグのため、ボルトのみの締結版＝`dowel_angle=999`）
- **★8/25、そのまま組み立てに入り、レール2枚を残して組み上がった。** スペーサ＋ベース板をM3×15でモータフランジへ共締めし、モジュールをM4で締結。**ガタなし**
- **★8/25、モジュール側のM4ねじ穴が実測6.0mmしかなく、設計の見込み7.3mmより浅かった。** M4が底突きして締まらない症状が出たが、**平ワッシャー0.8mm×2枚を頭に挟んで解決**。詳細は§4の8/25
- **★8/26、機構が完成（レール取り付け完了）。測定2完了：`s_alpha=+1`。座標系の符号が完全確定**
- **★8/26、閉ループ制御プログラム`src/BalanceControl`を新規作成し、初めて実際にモータへトルクを送った。** ゲイン倍率0.3で試したところ、**振子（α）は±2.8°以内で安定して上向きを保った**が、**アーム（θ）が復元力不足でじわじわ流れ、安全装置（±40°）で自動停止**。原因は判明済み（摩擦補償の偏りにアーム側ゲインが負けた）
- **★★8/26、LQRのBryson重みを見直し（θの許容偏差0.5→0.10rad）、実機で約30秒の連続保持に成功。** ゲイン倍率1.0でも同じ症状（アームが流れる）が再現し、摩擦補償を切る／K要素を個別に手で強める、という2つの対処はどちらも悪化させた。根本原因は`design_and_simulate.py`のBrysonの重み設定（θを実質無視するQ）にあり、Python側で重みを絞ってKを再設計したところ解決。**アーム角の安全ガードも±40°→±140°に拡大**（メンバーCがケーブルを整理し、その範囲でも問題ないことを確認済み）。詳細は§4の8/26
- **★8/26、制御周期が突然崩壊し激しく振動する事象が2度発生したが、同日中に原因を特定・確定した。「コマンドプロンプト以外のウィンドウをクリックすると発生する」**（Windows 11がフォアグラウンドでないプロセスのタイマ分解能要求を無視するため）。制御則の問題ではない。**未対策なので、実演・発表時は絶対に他のウィンドウをクリックしないこと。** 詳細は§4の8/26
- **★★★8/26、スイングアップ（振り上げ→キャッチ）に成功。しかも2回連続。** `src/SwingUp`を新規作成。振子が真下で静止するのを自動検出→エネルギー整形則で振り上げ→上向き付近でLQR（キャッチ）に切り替え→15秒前後の安定保持、まで人手を介さず到達。**どちらの回も安全ガードには一度も達していない。** 2回目は動画（`IMG_0300.MOV`）に記録済み。詳細は§4の8/26
- **★★動作確認済みコードを`8月26日分/動作確認済みコード_20260826/`に退避済み。** 以降の調整で悪化したら、同フォルダのREADME.mdに従って戻せば必ず動く状態に復帰できる
- **★8/26夕方に揺れの調整も完了**：Brysonのθ̇許容偏差を3.0→1.5rad/sにしてK再設計。保持中のアームの揺れ幅が40〜84°から約9°（−6°〜+3°）に縮小。この設定でスイングアップから114.7秒の連続保持を確認
- **★8/26夜に振子角の測定がずれる問題が出たが、8/27に解決した。** 原因は4極ジャックの接触不良（間欠断線）。**8/26夜にメンバーBが代理で来てはんだ付けを止め直し、8/27に読み取りが正常化したことを確認済み。**
- **★8/27、ハード側の疑いをすべて潰した。** 配線・エンコーダの読み取り・アーム側の摩擦（実測0.154 N·m、過去0.147とほぼ同じ）・振子側の摩擦（自由振動48秒、むしろ低い）はいずれも正常。**QUBEモジュールやモータに損傷・劣化は起きていない**
- **★★★8/27午後、振り上げの「頭打ち」の原因を特定した。SwingGainが小さすぎた。** エネルギー整形則のトルクは真上に近づくほどゼロに向かうため、キャッチ条件の25°付近では押す力0.019 N·mに対し摩擦残差が約0.015 N·mとほぼ拮抗していた。**SwingGainを15→30にしたところ5回中5回成功**（直前の8回は7回が頭打ち）。53回の試行記録つき。詳細は§4の「8/27 午後」
- **★★ただしコードの既定値は15.0のまま（8/27は時間切れ）。当面は `dotnet run --project src/SwingUp -- COM4 COM5 30` と引数で30を渡すこと。** 8/28に既定値を変更する
- **★試行結果は `src/SwingUp/trial_log.csv` に自動記録される**（成功／キャッチ失敗／頭打ちを自動分類）。8/27時点で53回分
- **★予定（8/28時点）：今日で調整を終わらせたいが、無理はしない。8/31（月）を予備日とし、調整が終わればポスター制作へ移る。** 今日も15:40に作業を切り上げて片づけ。作業リストは§7

---

## 1. プロジェクト概要

- 探究＝研究室配属（指導教員研：ロボットアーム・自動制御車いす等）の体験版
- 目標構造：最低限（調べ学習・第3回レポートで提出済み）→ モータ制御（8/6達成）→ 倒立振子（現在）
- **やり取りは日本語で行うこと**

### チームと役割

| 担当 | 内容 |
|---|---|
| メンバーA | 機構製作、システム統合、部品選定、マイコン側（STM32）の実装 |
| メンバーB | 運動方程式・制御則、C#実装、摩擦/振子パラメータ同定、機構設計、シミュレーション |
| メンバーC | 振子エンコーダ関連（8/19から合流） |

---

## 2. システム全体の構成

```
[QUBE振子モジュール]
  └ エンコーダ E8T-512（5V, A相/B相）
      └ 3.5mm 4極プラグ
          └ 4極ジャック（ユニバーサル基板に実装、8/19完成）
              └ NUCLEO-G474RE（★D7=A相 / D8=B相 / 5V / GND）※8/21にA相をD9→D7へ変更
                  └ USB(Micro-B) 仮想COM 921600baud → PC
                     13バイトフレームを1kHzで送信

[DM-J4310-2EC モータ]
  └ CAN → USB-CANアダプタ → PC（C#制御プログラム）
  └ 出力フランジ → 3Dプリントアダプタ → QUBE振子モジュール

           ↓ 両系統ともPCの同じプログラムに入る（8/21に接続完了）
      PendulumTelemetry（C#）で受信 → オブザーバ → LQR計算
```

**PCには USB が2本挿さる。必ず同じPCであること**（LQR計算に振子角とアーム角の両方が同時に要るため）。
- USB Micro-B → Nucleo（振子角、PCへの一方向、1kHz）
- USB → USB-CANアダプタ → モータ（トルク指令とアーム角・角速度、往復）

**アーム角はモータ自身のCANフィードバックから取る。**エンコーダをマイコンに繋いだのは振子角用のみ。
状態量4つの内訳：θ・θ̇＝モータのCANフィードバック／α＝エンコーダ経由／α̇＝オブザーバが推定。

**注意：2本のUSBが同じPCに入ることで、モータ側とエンコーダ側のGNDがPC経由で繋がる**（グランドループ）。
モータのノイズがここを通る可能性があるため、**エンコーダのケーブルとモータの電源ケーブルを平行に束ねないこと**。

---

## 3. 確定している技術情報

### 3.1 モータ DM-J4310-2EC V1.1（Damiao）

| 項目 | 値 |
|---|---|
| CAN ID | 4 |
| 減速比 | 10:1 |
| 制御モード | MITモードに設定済み（フラッシュ保存済み、電源再投入後も維持） |
| P_MAX / V_MAX | 12.5 / 30（CAN経由で直読して確認済み） |
| **T_MAX** | **10 → 2.0 N·m に変更済み**。12bit分解能が4.9 → 0.98 mN·m と5倍細かくなった |
| 静止摩擦 | **0.147 N·m**（T_MAX変更後の再測で0.137、7%以内で整合） |
| 動摩擦 | **0.126 N·m**（正転0.109／逆転0.143、30%の非対称） |
| 粘性摩擦 | **0.027 N·m·s/rad** |
| 制御周期 | **300 Hz採用**（実測平均3.333ms、標準偏差0.563ms、取りこぼし0%） |
| 制御周期の上限要因 | USB-CANの往復遅延 約2.3ms。500Hzは追いつけず実質436Hz |
| 逆駆動テスト | 合格。失能時と使能時（トルク0）で感触に差がなく、寄生トルクなし |

**T_MAX変更時の教訓**：レジスタを書き換えただけでは指令とフィードバックの解釈が整合しているか分からないため、**既に測ってある静止摩擦を測り直して同じ値が出るかで検証**した。また変更は**モータ側→コード側の順**で行うこと（逆順だと同じ指令値が数倍のトルクとして解釈されて危険）。

#### 出力フランジの寸法（公式図面＋実測で確定）

| 項目 | 値 |
|---|---|
| 回転する出力フランジの外径 | **Ø34.95**（メンバーAが実測） |
| ボルト円（PCD） | **Ø27**、6×M3、深さ5mm |
| 位置決めピン穴（大） | 3×Ø4（+0.02/+0.04）、PCD **Ø24.30** |
| 位置決めピン穴（小） | 2×Ø3（+0.02/+0.04）、深さ5mm、基準から15° |
| フランジの出っ張り | **1 mm**（実測。図面の45/46の差と一致） |
| 固定側ハウジング | Ø50 に 6×M3（**使わない**） |
| 背面（固定治具用） | Ø38 に 4×M3、深さ4mm |
| モータ本体外径 | Ø57 |

公式マニュアル：https://damiao.enactic.ai/assets/files/dm-j4310-2ec-v1.1-zh-5d089e0b013d8e2fc203c5b670008a66.pdf
（p.4「电机尺寸及安装」に寸法図。中国語版。ページを画像化して読む必要がある）

**注意**：図面の「Ø27」はフランジ自体の外径ではなく**M3ねじ穴の配置円（PCD）**。「Ø24.30」は位置決めピンの配置円。ここは一度誤読した箇所。

### 3.2 振子モジュール（QUANSER QUBE-Servo 2）

- 先生からの**借用品**。振子モジュールのみで、本体キューブは無い
- **分解しない・強い力をかけないこと**
- エンコーダ：**US Digital E8T-512-250-S-H-M-B**（512 CPR → 4逓倍で2048カウント/回転）
- 出力は5V・TTLプッシュプル（High約4V）

#### ケーブル（3.5mm 4極プラグ）のピン配置 ← テスターで実測確定

| プラグの位置 | 信号 | ジャック側ケーブルの線の色 | Nucleoへのジャンパの色 |
|---|---|---|---|
| 先端（チップ） | **5V** | 赤 | 赤 |
| 2番目（リング1） | **A相** | 白 | 白 |
| 3番目（リング2） | **B相** | 緑 | 緑 |
| 根本（スリーブ） | **GND** | 黒 | 青 |

エンコーダ本体の刻印「1 5V A G B」とも一致している。
線の色は8/19にテスターで実測して確定した（`IMG_20260819_124456.jpg` に図あり）。
**GNDだけ、ケーブル側が黒・ジャンパ側が青**なので混同しないこと。

#### 振子のパラメータ（メンバーBが実測・同定）

| パラメータ | 値 | 出所 |
|---|---|---|
| 振子全長 | 128.70 mm | 実測 |
| ピボットより上 | 7.0 mm | 実測 |
| l_p（ピボット→重心） | 57.35 mm | 上記から算出 |
| J_pivot | 1.123×10⁻⁴ kg·m² | 自由振動 T=0.5730 s から |
| J_p（重心まわり） | 3.33×10⁻⁵ kg·m² | 同上 |
| b_p（振子軸の粘性） | 2.45×10⁻⁵ N·m·s/rad | 対数減衰 δ=0.0624/往復 |
| 不安定極 | 11.17 rad/s（時定数 約90ms） | モデルから |

幾何形状からの予測（J_pivot = 1.121×10⁻⁴）と周期からの逆算が **0.17%で一致**。

#### アーム側のパラメータ（8/17にメンバーBが実機測定）

| パラメータ | 値 | 出所 |
|---|---|---|
| J_arm（アーム＋アダプタ＋モジュールの回転慣性） | **2.13×10⁻³ kg·m²** | 6 / 8 / 9 Hz の3点が3%以内で一致 |
| 同上のばらつき | 1.95〜2.37×10⁻³ | 摩擦係数の仮定を実測値の前後に振った場合 |

これで制御則の設計に必要な慣性値が、振子側・アーム側とも実測で埋まった。

### 3.3 マイコン NUCLEO-G474RE

先生が1年生の「デザイン」という授業用に購入されたものの余り。7号館の部品ボックスから借用。

| 項目 | 値 |
|---|---|
| 基板型番 | MB1367C（シルクに`NUCLEO-G474RE` / `NUG474RE$AT4`） |
| MCU | STM32G474RET6、Cortex-M4 @170MHz、Flash 512KB、LQFP64 |
| デバッガ | ST-LINK/V3E（SN: 002A00353235510A37333439、FW V3J17M11） |
| USB | **Micro-B**（`CN1 USB STLK`）。ESP32用に用意していたケーブルがそのまま使える |
| COMポート | COM4（環境依存） |
| コネクタ | Arduino Uno V3互換（CN5〜CN9）＋ ST Morphoヘッダ（CN7・CN10） |

#### ★重要：5Vトレラントなピンとそうでないピン

データシート **DS12288 Rev 6 の Table 12（pin definition）の「I/O structure」列**で判定する。

| ピン | I/O structure | 5V直結 |
|---|---|---|
| PA3〜PA7、PB0〜PB2、PC5 など**ADC入力を持つピン** | `TT_a` | **不可（3.3Vのみ）** |
| **PC6・PC7** | `FT_f` | **可** |
| **PA8** | `FT_a` | 可 |
| **PA9** | `FT_fda` | 可（ただしUCPDのデッドバッテリー用プルダウンが起動時に有効。"d"がその印） |
| PC4 | `FT_fa` | 可 |

**「STM32は5Vを受けられる」は多くのピンで正しいが、全ピンではない。** 当初PA6/PA7（TIM3_CH1/CH2）を推奨しかけたが、これは`TT_a`で5Vトレラントではなく、そのまま繋いでいたら破損の恐れがあった。**必ずこの表で確認してから配線すること。**

#### Arduinoのピン番号との対応（実際の変換定義ファイルで確認済み）

| Arduino名 | STM32ピン | I/O structure | 備考 |
|---|---|---|---|
| **D7** | **PA8** | `FT_a` 5V可 | **★現在A相に使用（TIM1_CH1）** |
| **D8** | **PA9** | `FT_fda` 5V可 | **★現在B相に使用（TIM1_CH2）** |
| D9 | PC7 | `FT_f` 5V可 | 8/19までA相に使っていた（TIM3_CH2/TIM8_CH2） |
| D10 | PB6 | | |
| D11 | PA7 | `TT_a` | **5V不可** |
| D12 | PA6 | `TT_a` | **5V不可** |
| D13 | PA5 | | **基板上の緑LED（LD2）** |
| （番号47） | PC6 | `FT_f` 5V可 | TIM3_CH1/TIM8_CH1。**Morphoヘッダ側で場所を特定できていない** |

出典：https://github.com/stm32duino/Arduino_Core_STM32 の
`variants/STM32G4xx/G473R(B-C)T_G473RETx(Z)_G474R(B-C-E)T_G483RET_G484RET/variant_NUCLEO_G474RE.h`
および `PeripheralPins.c`（TIMの割り当てとAF番号はこちらで確認できる。PA8/PA9 は `GPIO_AF6_TIM1`）

#### ★ピンの物理的な並び（8/21に2回挿し間違えた）

`D0〜D7` は **CN9**、`D8〜D15` は **CN5** という別のヘッダだが、基板上は端と端が繋がって
**1本の連続した並びに見える**。境目は見た目では分からない。

```
… D5 - D6 - D7 | D8 - D9 - D10 …
              ↑CN9とCN5の境目
```

**D7 と D8 は隣同士。D9 はそこからもう1つ先。**
「D9→D7に移す」場合、**D8を1つ飛び越える**必要がある。ここを間違えてA相をD8に挿すと、
B相と同じピンを取り合う形になり、カウントが動かない（実際に起きた）。

#### エンコーダモードで使えるピンの組（5Vトレラント必須）

| タイマ | CH1 | CH2 | ビット幅 | 備考 |
|---|---|---|---|---|
| **TIM1** | **PA8 (D7)** | **PA9 (D8)** | 16bit | **★採用。両方Arduinoヘッダ上で扱いやすい** |
| TIM3 / TIM8 | PC6 | PC7 (D9) | 16bit | PC6の場所が未特定 |
| TIM2 / TIM5 | PA15 など | PB3 (D3) など | **32bit** | 5Vトレラントか未確認。PA15はMorpho側 |

**16bitでも問題ない。** 1kHzでサンプリングして**16bitの差分を`int16_t`にキャストして積算**すれば、
ラップは自然に吸収される（1msの間に16回転しない限り厳密）。オーバーフロー割り込みは不要。

### 3.4 開発環境（Arduino IDE）

先生の助言でSTM32CubeIDEからArduino IDEに切り替えた。

| 項目 | 設定 |
|---|---|
| IDE | Arduino IDE 2.3.10 |
| 追加ボードURL | `https://github.com/stm32duino/BoardManagerFiles/raw/main/package_stmicroelectronics_index.json` |
| ボードパッケージ | STM32 MCU based boards 3.0.0（STMicroelectronics） |
| ツール→ボード | Nucleo-64 |
| ツール→Board part number | Nucleo G474RE |
| ツール→ポート | COM4 |
| ツール→Upload method | **Mass Storage** ← 8/19に変更 |

**STM32CubeIDE 2.2.0 は8/17にアンインストール済み**（3.38GB）。作業フォルダ`C:\Users\<ユーザー名>\STM32CubeIDE`も削除。
**`STMicroelectronics stlink-server`（3.70MB）は残してある**。

#### ★8/19：書き込み方式を Mass Storage に変更した

STM32CubeIDEをアンインストールした際、**同梱されていた STM32CubeProgrammer も一緒に消えていた**。
そのため SWD 書き込みが `STM32CubeProgrammer not found (STM32_Programmer_CLI.exe)` で失敗する。

**対処：ツール→Upload method を `Mass Storage` にする。** 追加ソフトの導入は不要。
NUCLEOはUSBに挿すと `NOD_G474RE (D:)` というドライブとして見えるので、そこへのコピーで書き込まれる。
`C:\Program Files\STMicroelectronics` と `C:\ST` を探索したが Programmer の残骸は無い（確認済み）。

**次に誰かが書き込むとき、SWDのままだと同じエラーで止まる。**

### 3.5 開発環境（C#・PC側）★8/21構築

| 項目 | 設定 |
|---|---|
| .NET SDK | **10.0.400**（`C:\Program Files\dotnet`。8/21に導入） |
| プロジェクト | `8月21日分/メンバーBリポジトリ_20260821/探求/モータ制御プログラム一式_20260806/csharp` |
| ターゲット | `net10.0`、`ImplicitUsings` / `Nullable` とも enable |
| 依存 | `System.IO.Ports` 10.0.10（NuGet。`DamiaoCan.csproj`で参照） |
| COMポート | **COM4＝振子エンコーダ（Nucleo）／COM5＝モータ（USB-CAN、CH340）** |
| ボーレート | エンコーダ 921600 / USB-CAN のPC-アダプタ間 2Mbps |

**ビルド・テストの確認済み状態**（8/21、メンバーAのPCで実施）

```
dotnet build      → 成功（0警告0エラー）
dotnet test       → 88件全合格（メンバーBのMacと同じ結果を再現）
```

#### プロジェクト一覧

| プロジェクト | 作者 | 内容 |
|---|---|---|
| `DamiaoCan` | メンバーB | ライブラリ本体。CAN通信・MITフレーム・モータ制御 |
| `DemoOneTurn` | メンバーB | 1回転デモ。**今の機構では配線が引っかかるので使わないこと** |
| `SetControlMode` / `BackdriveTest` / `FrictionTest` | メンバーB | モード設定・逆駆動試験・摩擦測定 |
| `TorqueCalibration` | メンバーB | トルクスケール校正 |
| `OpenLoopSwing` | メンバーB | 振子センサ不要の共振加振・周波数掃引・慣性測定 |
| **`SweepTest`** | **メンバーA 8/21** | **±90°往復（`--`なし）と保持モード（`-- COM5 hold`）** |
| **`PendulumTelemetry`** | **メンバーA 8/21** | **振子角+アーム角の同時受信、オブザーバ、LQR計算（表示のみ）** |
| **`SignCalibration`** | **メンバーA 8/24** | **★座標系の符号（s_theta / s_alpha）を実測で決める。このプロジェクトで初めてモータへ非ゼロトルクを送ったツール** |
| **`BalanceControl`** | **メンバーA 8/26** | **★★倒立保持。u_totalを実際にモータへ送る初のプログラム。** 引数でゲイン倍率/摩擦補償倍率/θ復元力倍率を個別に指定できる（切り分け用。通常はすべて1.0） |
| **`SwingUp`** | **メンバーA 8/26** | **★★★スイングアップ。真下で静止するのを自動検出→エネルギー整形則で振り上げ→上向き付近で`BalanceControl`と同じLQRへ切り替え** |

#### `SignCalibration` の使い方（8/24作成）

```
dotnet run --project src/SignCalibration -- COM4 COM5     測定1・測定2（トルクを送る）
dotnet run --project src/SignCalibration -- --watch-theta COM5   θ監視のみ（トルクを送らない）
dotnet run --project src/SignCalibration -- --watch-alpha COM4   α監視のみ（モータ不要）
```

- **測定1（s_theta）**：t_ff=+0.2N·m を300ms。モータ報告位置が増える向きでs_thetaを決める。**モジュールがアームに固定されていなくても実行できる**
- **測定2（s_alpha）**：t_ff=+0.3N·m を50ms。カウントの増減でs_alphaを決める。**モジュールがアームに固定されていないと測れない**（8/24にΔ0カウントで確認済み）
- 安全策：開始角から**±20°**を超えたら即打ち切り。各測定後トルク0で減速してから失能
- 監視モードは、固定できない状況で手動判定するために用意したもの。ただし**+θ（＝+e_t）と+αは回る軸が違う**ため手動照合は誤りやすい。**自動測定が使えるならそちらを優先すること**

#### ★Motor クラスの使い分け（8/21に学んだ重要な点）

| メソッド | 所要時間 | 用途 |
|---|---|---|
| `ReadStatus(tries)` | **1回で最大100ms超** | 起動時の疎通確認だけに使う。**定周期ループでは絶対に使わない** |
| `TorqueCommand(0.0)` ＋ `ReadFeedback(timeout)` | 数ms | **定周期ループはこちら。**「送信→即座に読む」を1組にする |

`ReadStatus()` は「一旦失能させて応答を待つ」実装のため重い。
これで回すと更新レートが**9〜19Hz**しか出ず、300Hz前提のオブザーバゲインでは即発散する。
`TorqueCommand(0.0)`＋`ReadFeedback()` に変えて**128Hz前後**まで改善した。

**トルク0ならモータは動かない。** CLAUDE.mdの「kp=0, kd=0, t_ff=0 なら指令トルクが0なので
動かないのは当然の挙動」がこれ。8/6の逆駆動テストでも寄生トルクなしを確認済み。

---

## 4. 経緯（時系列）

### 8/6：モータ制御（Python）
CAN通信を確立。速度モード・MITモードで動作確認、1回転を正確に制御。

### 8/10：C#移植・QUBEモジュール受領
メンバーBがPython版をC#に全面移植。先生からQUBE-Servo 2の振子モジュールを譲り受けた。
この日作った計画書PDFは、QUBE受領前の内容のため**現在は古い**（先生には未送付）。

### 8/11：エンコーダ配線の確定・摩擦問題の発覚
- エンコーダの正体特定、プラグのピン配置をテスターで実測確定
- メンバーBがモータの摩擦を実測。「必要な定常トルク0.014 N·m に対し摩擦0.147 N·m で約10倍」→ **一度「成立しない」と判断**
- 先生に「倒立振子が厳しいことが分かった」と報告

### 8/12：判断の誤りを特定、倒立振子で続行が決定
先生から「クーロン摩擦は補償が簡単なのでそんなに影響ないですよ」との助言。メンバーBが前提から検証をやり直し、**4件の判断の誤り**を特定した。

1. **「摩擦が必要トルクの10倍だからアーム延長300mmが必須」→ 誤り**
   比べるべきは「必要な定常トルク 対 摩擦」ではなく「**使えるトルク 対 摩擦**」。モータは2.0 N·m出せるので、摩擦は越えられない壁ではなく打ち消すべき外乱。
   さらに、素の寸法で転倒した最初のシミュレーションは**改造後のプラント用に調整したゲインを流用した不公平な比較**で、対照実験（摩擦ゼロ）でも0.04秒で転倒していた。
   → **アーム延長ブラケット（215mm）、錘（150g）、アルミ加工はすべて不要になった**
2. **「摩擦補償は必須」→ 必須ではない**
   Karnoppモデル（真の固着あり）では補償なしでも成立（1.69°）。固着ありの方がリミットサイクルが小さい（0.41° 対 0.96°）。静止摩擦は「その場に留める」問題では味方に回る。ただし前滑り変位は表現しきれないため、補償は入れる方針は維持。
3. **「スリップリングが必要」→ 不要**
   エンコーダのケーブルはブロック側から出ており、回転するのは銀の丸棒。サービスループ（たるみ）で足りる。
4. **「取り付け平面を下に伏せて板に載せる」→ 不可能**
   取り付け平面は円筒に3.5mm掘り込まれた窪みで、円筒面の方が外側に出ている。→ 円筒面で受け、M4で締結する構成に変更。

この日、**計画書（PDF）と部品発注のお願いを先生に送付**。その後、先生から「マイコンは7号館の部品ボックスにあるSTM32G474REを使ってください。STM32は5Vを受けられるので多分大丈夫」との返信があり、ESP32とレベル変換モジュールが発注リストから外れた。

### 8/14：マイコン環境構築＋エンコーダ動作確認（メンバーA）／共振測定（メンバーB）

**メンバーA側**
- Arduino IDEの環境構築（ボードパッケージ導入、書き込み設定）
- 5Vトレラントなピンをデータシートで確認 → PA6/PA7が不可と判明、D9(PC7)・D8(PA9)を採用
- 振子モジュールをジャンパー線で仮結線し、**軸を回すとマイコン側で検知できることを実機で確認**

**メンバーB側**
- **振子エンコーダ未着荷のまま、モータのフィードバックだけで振子の固有振動数を測定することに成功**
  - 方法：アームをMITモードの位置制御で正弦波駆動し、周波数を掃引。振子が共振すると反力がアームに返り、位置制御の負荷が変わる
  - 結果：トルクRMSに1.60Hzのピークと1.80Hzのディップの対が現れ、**遷移点＝固有振動数は1.70Hz**
  - **自由振動から予測した1.745Hzと3%以内で一致**。これによりモデルの正しさ・アダプタがトルクを伝えていること・組み立ての健全性の3点が同時に裏付けられた
- モータ図面の確定、アダプタ設計の確定（v8）
- 校正用の錘が340〜510gの金属から**PLA製100g**で足りることが判明（摩擦の非対称量は実測済みなので解析側で差し引ける）

### 8/17：環境整理・資料確認（メンバーA）／アーム慣性の実測（メンバーB）

**メンバーA側**
- STM32CubeIDEのアンインストール、作業フォルダの削除
- 先生から共有された「デザイン実習資料」3点の内容確認（§6参照）

**メンバーB側**（報告：`作業報告_メンバーB_20260817.md`）
- **アームの慣性モーメントを実機測定**：J = 2.13×10⁻³ kg·m²。6/8/9Hzの3点が3%以内で一致し、摩擦係数の仮定を振っても1.95〜2.37×10⁻³に収まることを確認
- **バグ2件を修正**
  1. 加振ツールが目標角を**モータ内部の絶対角**で指令していた。そのままなら実機に**143°の引き戻し指令**が出るところだった。中心を実測位置に合わせ、開始角から一定以上ずれたら打ち切るガードを追加
  2. オブザーバの観測雑音を**量子化誤差だけ**で見積もっていた。実機の**タイミングジッタ由来の誤差が量子化の7倍**あった。これを入れるまでは、慣性を実測値に更新した時点で**全ケース転倒**していた
- **土台を組み立てた**。金属板の大きさがちょうど振子と干渉しない程度だったので、モータを何かの上に載せて高くすれば机との干渉は解決できる見込み（§7の「固定治具」が軽くなった）

### 8/18：先生から連絡
- 「4極ジャック購入しました．今日明日中には7号館の机の上においておきます．」（11:07）

### 8/19：★振子角の読み取り〜PC送信が完成（3人揃っての作業）

**冒頭に3人で決めた取り決め**（現物の紙：`IMG_20260819_124456.jpg`）

- **振子角：先端から見て、真上が0°、時計回りが正**
- **アーム角：上から見て、時計回りが正**

※振子角の原点が**真上**であることに注意。メンバーBの模型の「α=π が真下（＝α=0 が真上）」と一致している。
- 単位：**生カウント（int32累積、剰余を取らない）**。度への変換はPC側
- 分解能：E8T-512の4逓倍 = 2048 count/rev（0.176°/count）。メンバーBの検証で「8倍粗くても成立」と確認済みなので変更不要
- 送信：**1 kHz、タイムスタンプ付き、ハードウェアタイマ割り込み**。300Hzへの同期は不要

**実装したこと**
- ジャックをユニバーサル基板にはんだ付け（メンバーC）。テスターでピン対応を確定
- ソフト割り込みによる4逓倍カウント（メンバーA）
- 13バイトのバイナリフレーム送信（sync 0xA5A5 / seq / t_us / count / CRC-8）

**実測結果（メンバーBのオブザーバ設計への入力）**

| 項目 | 実測 | 要件 | 判定 |
|---|---|---|---|
| 実効レート | 1000.1 Hz | 1 kHz | ○ |
| CRC不一致 | 0 | — | ○ |
| フレーム落ち | 0（0.000%） | — | ○ |
| サンプリングジッタ | **標準偏差 0.1 µs** | 2ms以下が望ましい | ○ 桁違いに余裕 |
| 伝送遅延 | **平均1.05 ms** / 最大34 ms | 10ms以下、破綻点40〜50ms | △ 典型値は良好 |

- 高速5回転試験：理論10240カウントに対し実測10230（差10カウント=1.76°）→ **取りこぼし無し**。ソフト割り込み方式で確定
- 時計回りで数値が増加 → 決めた符号と一致。A相B相の入れ替え不要
- 伝送遅延の最大34msはPythonスクリプトでの計測値。**C#実装時に再測定が必要**。ただしタイムスタンプによる外挿で吸収できる設計になっている
- 計測の注意：受信側で待ってから読むと、その待ち時間がそのまま「遅延」として出てしまう。`in_waiting`で来ている分だけ即座に読むこと（最初この誤りで最大220msという無効な値が出た）

### 8/20：先生からご指摘（非作業日）

> 「ソフトウェア割り込みはやめたほうがいいです．遅延が大きく，4逓倍で使おうとするとさらに遅延が大きくなるうえに，モータを動かしながらだとノイズによる誤動作がかなり入ります．タイミングを見てTIMエンコーダカウントモードに移行するのがおすすめです．」

8/19の「取りこぼし無し」はモータ**停止**時の結果であり、稼働時のノイズは未検証だったため、指摘は的確だった。

### 8/21：TIM1移行、ノイズ耐性の実測、C#環境構築（3人揃っての作業）

**機構側（メンバーB）**
- モータの固定・かさ上げが解決。完成図の通り電源の上に固定する構成で確定（新規の治具設計は不要になった）
- ケーブル延長（電源→モータ間が短すぎた分。メンバーCが対応）

**マイコン側（メンバーA）**
- **TIM1エンコーダモードへ移行**（配線：A相をD9→D7に変更。B相D8はそのまま）。入力フィルタ最大設定
  - 1回転：−3→2045（差2048、**誤差0**）
  - 高速5回転：−3→10237（差10240との差3）。ゆっくり戻すと−4（開始との差1カウント）
  - **8/19のソフト割り込み版（誤差10カウント）より精度が向上**
- 配線ミス（A相ジャンパの挿し忘れ／D7とD9の位置誤認）を2回経験。**D7はCN9の最後、D8はCN5の最初で物理的に隣接、D9はさらにもう1つ先**という正確な並びを確認

**C#側（メンバーA。本来はメンバーBの担当領域だが、メンバーB合流前に先行して着手）**
- .NET SDK 10.0を導入。**ユーザー領域(`%USERPROFILE%\.dotnet`)とシステム領域(`C:\Program Files\dotnet`)の両方に入れる二度手間になった**（後述の教訓参照）
- メンバーBの`DamiaoCan`ライブラリ（8/10版 `csharp.zip`）を使い、`SweepTest`という新規プログラムでモータ動作を確認
  - 通信確認 → ±90°のゆっくりした往復（1回転はしない。エンコーダケーブルが引っかかるためメンバーBの指示で禁止）
  - **成功。C#からモータを動かせることを確認**

**モータ稼働時のノイズ耐性テスト（今日の核心）**
- 最初、±90°往復中に振子が目に見えて揺れた。→ **これはノイズではなく、折り返し時の加減速による本物の力学的結合**と判明（電気ノイズと物理的揺れが混ざって区別できなかった）
- そこで`SweepTest`に**保持モード**（`-- COM5 hold`）を追加。**アームを動かさず、その場でMIT/PD制御のPWMだけを送り続ける**ことで、物理的な動きを排除して電気ノイズだけを分離
- 振子を手で止めてから保持モードを実行 → **カウント値は完全に一定のまま変化なし**
- **結論：この構成（TIM1＋入力フィルタ最大）では、モータ稼働時のノイズによる誤カウントは発生しない。先生の指摘に対する実測での回答が出た**

#### 教訓：.NET SDKのインストール（時間を溶かした点）

- 最初ユーザー領域にインストールしたが、**PCにはすでに `C:\Program Files\dotnet` にSDKなしの壊れたインストールがあり、Windowsのシステム側PATHがユーザー側PATHより先に検索されるため、新しい方が隠れてしまった**
- 対処は、管理者権限で `C:\Program Files\dotnet` に正しくインストールし直すこと。**UAC確認画面はメンバーAさん本人の操作が必要**（自動化ツールからは押せない）
- 教訓：新しいPCで開発環境を作るときは、**先に `dotnet --list-sdks` 等で既存インストールの有無・破損の有無を確認してから**インストールした方が早い

#### メンバーBの集中講義が判明 → 開発体制が変わった

8/24〜28の平日5日間、メンバーBは集中講義（2〜4限、10:30〜16:10）。**昼休みに進捗を見に来るのは可能だが、一緒に作業するのは無理。**
→ **以降はメンバーAのPCで単独で進める方針に切り替えた。**

そのため**メンバーBのリポジトリ全体を当日中に共有してもらった**（`8月21日分/メンバーBリポジトリ_20260821/`）。
これをやっておかないと、メンバーBがいなくなってから「あのファイルが無い」で詰む。

- 8/10版の`csharp.zip`は`TorqueCalibration`と`OpenLoopSwing`が無い**古いもの**だった
- **今後は `メンバーBリポジトリ_20260821` を正とする**
- メンバーAのPCで `dotnet build` 成功、`dotnet test` **88件全合格**（メンバーBのMacと同じ結果を再現）
- 展開時に `sim/.venv`（Mac用バイナリ）と `bin`/`obj` は削除した。20MB → 1.9MB

#### C#側の受信実装（`PendulumTelemetry`）— 本日最大の成果

新規プロジェクト `src/PendulumTelemetry/` を作成。**振子角（マイコン経由）とアーム角（モータのCANフィードバック）を同時に受信し、オブザーバとLQRの計算まで通した。**

- `PendulumEncoderReader.cs` … 13バイトフレーム（0xA5A5 + CRC-8）の受信。CRC誤り数・フレーム落ち数もカウント
- `FurutaObserver.cs` … `FurutaGains`のA/B/K/Lと`design_and_simulate.py`の制御ループをC#で再現
- `Program.cs` … ゼロ点校正 → 受信 → 推定 → **u_totalを表示（送信はしない）**

**結果：発散せず、振子角−15°〜+22°の範囲で物理的に自然な数値が出るところまで到達。**

**★`FurutaGains.cs` は `model/` にあるだけで、C#プロジェクトには入っていなかった。**
`csharp/src/DamiaoCan/` にコピーして初めてビルドが通る。メンバーBがゲインを再生成したら、**毎回このコピーが必要**。

#### ★★ ここで踏んだ3つの罠（同じところで詰まらないために）★★

**罠1：`ReadStatus()` は定周期ループに使ってはいけない**

`Motor.ReadStatus()` は「一旦失能させて応答を待つ」実装で、**1回あたり最大100ms超**かかる。
これで回すと更新レートが**9〜19Hz**しか出ず、300Hz前提のオブザーバゲインでは即発散した。

→ 対処：`Enable()` してから **`TorqueCommand(0.0)` を送って即 `ReadFeedback()` で読む**方式に変更。
**128Hz前後**まで改善した。トルク0なのでモータは動かない（8/6の逆駆動テストで寄生トルクなしを確認済み）。
CLAUDE.mdの「kp=0, kd=0, t_ff=0 なら動かないのは当然の挙動」がまさにこれ。

**罠2：送っていないトルクを「送ったつもり」で予測すると発散する**

オブザーバの予測式 `x̂ ← x̂ + dt·(A·x̂ + B·u + L·(y − C·x̂))` の `u` に、
**計算しただけで実際には送っていない u_cmd** を入れていた。
モデルは起きていない動きを予測し、実測とのズレが次のu_cmdをさらに大きくし……という正のフィードバックで指数発散。

→ 対処：`Step()` に `appliedTorqueNm` 引数を追加し、**実際に送った値（＝常に0）**を渡すようにした。
**「計算はするが送らない」プレビューは閉ループ制御とは別物**、という理解が要る。

**罠3：平均レートが足りていても、まれな遅延で発散する**

罠2を直しても、まだゆっくり発散した。`A − L·C` の固有値を実際に計算したところ：

```
    -79.271 ± 78.292j     (|λ| ≈ 111)
     -8.026 ±  3.699j
```

前進オイラー法が数値的に安定なのは**おおよそ dt < 13ms**。平均128Hz（7.8ms）は満たしていたが、
**CAN応答がまれに遅れて13msを超えた瞬間だけ誤差が数倍に膨れ、それが蓄積して爆発**していた。
平均値だけ見ていては気づけない種類の不安定さ。

→ 対処：`FurutaObserver.Step()` 内で、**dtが大きいときは2ms以下に分割して複数回積分する**（測定値はその間一定＝零次ホールド）。これで安定した。

#### 未解決（次にやるとき最初に見る）

- ~~u_total に飽和が入っていない~~ **→ 8/21実装・実機確認済み**。`Math.Clamp`→`Math.Round`で±2.0N·mに頭打ちすることを確認
- **符号の向きが未検証。** `furuta_model.py` の座標系（θ・αの向き）と、8/19に実機で決めた「時計回りが正」が一致しているか未確認。**8/21、メンバーBへ確認メッセージ送付済み・返信待ち。これが済むまで、u_totalを実際にモータへ送らないこと**
- ~~表示に`-+0.00`のような二重符号~~ **→ 8/21確認：C#側の書式指定は正しく、再現なし。対応不要**
- ~~`メンバーBリポジトリ_20260821/探求/CLAUDE.md`の記述が古い~~ **→ 8/21修正済み**

#### 16時前、機構まわりの最終作業

- Ø4ピン穴の角度を実測し**30°で確定**（隣接するM3穴との中心間距離が実測6.875mm、理論値6.8mmと一致）
- `generate_qube_adapter.py`を実際に実行して検証。この環境のnumpyバージョンとの非互換（`np.cross`が2次元ベクトル非対応）を発見・修正
- **dowel_angle=30を有効にするとSTL生成が「形状の自己交差」エラーで落ちる新規バグを発見。** 数値上の干渉チェックには余裕があるため、角度の値ではなく「ピン穴を有効化するコードパス」自体の未修正バグ（今まで実行されたことがなかった）。原因未特定
- 対策として`dowel_angle`は999（無効）のまま維持。**8/24(月)の印刷はボルトのみの締結で進める**
- メンバーAが別途フォルダに置いた`qube_adapter_base.stl`/`qube_adapter_rail.stl`は、リポジトリ内の既存ファイル（8/14生成、ピン穴なし版）とバイト単位で完全一致することを確認。印刷にそのまま使って問題ない
- 16時前、作業終了。モータの正常終了・電源オフを確認して片付け

#### 16:00、Wrikeに進捗報告を送信

本日の作業内容（TIM移行、ノイズ耐性の実測、USB-シリアル遅延への対応と効果測定、C#受信実装、飽和処理、モータ固定の決定、L_r実測、ピン穴角度の実測）を箇条書きで報告。末尾に「次回（8/24 月）は座標系の符号を確認したうえで閉ループ倒立保持を試す」「符号が未検証のうちは計算結果をモータへ送らない」「ベース板の3Dプリントを行う」旨を記載し、**3Dプリンタの使い方を教えていただけるかを質問**した。

長文の末尾で埋もれたため、16:01に**@指導教員宛のメンションで質問だけ再送**している。→ 返信待ち。

なお、報告には以下を意図的に含めていない。
- **ピン穴を有効化するとSTL生成が落ちるバグ、numpyの非互換の件** … こちら側で解決すべき作業上の詰まりであり、結果として残る事実（ボルトのみで印刷する）は報告済みなので欠落はない

### 8/22（土・非作業日）：3Dプリンタの日程調整

先生から「日曜日から土曜日まで韓国なので、研究室の方A、研究室の方B、研究室の方Cで対応できるようでしたらお願いします」との連絡（8/21 20:00）。

- 研究室の方Bから「来週1週間はインターンで平日の対応は難しい。土日は研究室にいる」と返信
- **この「土日」が今週末（8/22-23）か翌週末（8/29-30）か読み取れず、メンバーAとAIで解釈が割れた。** 確認と並行して、研究室の方A・研究室の方Cへ平日の対応可否を質問
- 研究室の方Cから「**8/25(火)以外は研究室に行く予定**」と返信 → **8/24(月)11:00・7号館2階**に確定
- 研究室の方Cの指示：**STLの入ったPCを持参すること**

### 8/24（月）：3Dプリンタでの印刷、座標系符号の測定1（メンバーA単独）

**この日の作業時間は10:30〜16:00。11:00から研究室の方Cに3Dプリンタの使い方を教わり、そのまま印刷に入った。**

#### フォルダ整理

- `8月24日分/`を作成し、引継ぎメモを移動・改名（`引継ぎメモ_20260821.md` → `引継ぎメモ_20260824.md`）
- 印刷する4つのSTLを`8月24日分/`直下にコピー（`8月21日分/`にあった重複コピー2つは整理）
- **印刷直前に、4ファイルが現在のスクリプト出力と一致するか再検証。頂点座標は完全一致**（差は法線ベクトルの1×10⁻¹⁴mm規模のみ）。古いファイルの混入はなかった
- 旧試作（`qube_adapter_cradle.stl`、`keytile_peg5.8/6.8.stl`）はリポジトリ内に残っているが**印刷対象ではない**

#### ★プリンタの実体が判明：Markforged Onyx One

| 項目 | 内容 |
|---|---|
| 機種 | **Markforged Onyx One**（クラウド管理ツール Eiger 経由で操作） |
| 材料 | **Onyx**（ナイロン＋短繊維カーボン）。**PLAではない** |
| 場所 | 7号館2階。メンバーAが普段作業している部屋。**プリンタは今後も自由に使ってよいとのこと** |

**それまでの所要時間見積もり（一般的なPLA機を前提にした25〜35分など）はまったく当てにならなかった。** 必ずEigerの`Estimated Print Time`を見て判断すること。

#### 印刷実績（8/24）

| 部品 | 予測 | 結果 |
|---|---|---|
| `gauge` | — | **1時間10分**（完了） |
| `spacer` | 34分 | 完了 |
| `rail` 1個目 | — | 完了 |
| `rail` 2個目 | — | **16:00時点で残り1時間4分。稼働させたまま退室した** |
| `base` | **4時間** | **8/25に持ち越し** |

#### 印刷前に出ていた警告と、その扱い

- **メンテナンス警告**：`Plastic Nozzle`（3947cc超過）と`Plastic Bowden Tube`（4042cc超過）が両方「Due Now」。ただしプリンタ自体は`Ready`。研究室の方Cに確認して続行を判断した
- **材料不足の警告**：spacer（わずか1.71cc）ですら「Insufficient Material」が出た。**`Pause print when material is low`がONになっているため、切れたら自動で一時停止し、補充すれば再開できる**（Eigerの表示では所要5分程度）
- **交換用フィラメントの置き場所は8/24に教えてもらった。** 交換手順は「YouTubeを見れば分かる」とのこと

#### ★gauge実測の結果（このプリンタの寸法の癖）

| 測った箇所 | 公称 | 実測 | 差 |
|---|---|---|---|
| 穴の幅（レール間隔に相当） | 28.8mm | **28.70mm** | −0.10mm |
| 穴の長さ（旧設計の名残・参考値） | 42.8mm | **42.70mm** | −0.10mm |

- **両方きれいに−0.10mm。規則的な収縮で、反りなどの異常な兆候はない**
- レール間隔28.70mmは、モジュール円筒Ø28mmに対し**片側0.35mmの隙間**が残る（設計の狙いは0.4mm）。**問題なし**
- **★ただしgaugeは「穴」しか検証できない。** パッド（22.2mm角）やペグ（Ø5.8mm）のような**出っ張り側は未検証**。一般に出っ張りは大きめに出るため、**ペグ（モジュールのØ6穴に対し片側0.1mmしか余裕がない）はきつく出る可能性がある**
- 印刷に時間がかかる機種なので試し刷りの追加はせず、**きつければやすりで削って合わせる方針**とした

#### 組み立て用ねじの確認（8/24、すべて手元に確保）

| ねじ | 本数 | 用途 | 状況 |
|---|---|---|---|
| M3 なべ 全長16.7mm（頭2.0mm＝軸長14.7mm） | 5本 | スペーサ＋ベース板をモータ出力フランジへ共締め | **6本ではなく5本。** エンコーダのケーブル取り出し口と干渉する1箇所には付けられない。**★8/25判明：旧板6mmでは噛み合い4.7mmだったが、新板は8mmなので2.7mmに減る。M3×16（なべ、軸長16mm→噛み合い4mm）への変更を推奨。** 詳細は下記5b |
| M4 全長19.1mm | 1本 | ベース板下からモジュール側面のM4穴へ（主たる固定） | ベース板下面に少し出るが**何にも干渉しない**（実績あり） |
| M3 小ねじ ×25 または ×30 | 4本 | 側面レール2枚をベース板へ | 先輩から入手。**タッピングねじではない**が、Onyxはナイロン系でねじが効きやすいため、Ø2.6mmの下穴に**垂直・低トルクでねじ込んで自己タップさせる**方針 |
| スプリングワッシャー M3 | 4個 | 上記ねじの緩み止め | ねじ頭とレールの間に挟む。**輪が切れているのは正常な形状**。締める前は軸に対しゆるいのも正常 |

**★レール用ねじの長さについて、当初「6〜10mm」と案内したのは誤りだった。** レール自体の厚みが20mm（円筒の最大幅の高さまで届く必要があるため）で、ボルト穴はそこを貫通している。**レール20mm＋ベース板への食い込み分が必要なので、25mm以上でないと届かない。** 手持ちの3×16やM3×6では固定できない。

- **M3×25**：レールを抜けてベース板に5mm食い込む。下面に出ない。**4箇所とも同条件になるのでこちらを推奨**
- M3×30：ベース板を貫通し下面に約2mm出る。ただし**内側の穴もモータ軸から約25.9mm**（√(16²+20.4²)）でスペーサ半径17mmより外側にあるため、干渉はしない見込み

#### メンバーBから座標系の符号について回答（8/24）

**要点は「言葉での照合は決着しない。実測で決めろ」。**

- モデルのθは「上から見て反時計回り」が正で、メンバーAの取り決め（時計回り正）とは逆。ただしαについては「先端から見て」がどちら向きに顔を向けた状態かで結論が反転するため、言葉では詰め切れない
- **モデルには対称性がある**：(θ, α, u) を**すべて同時に**反転してもA・Bは完全に一致する（メンバーBが数値確認済み、差の最大値0.0）。**したがって鏡像なだけならK・Lはそのまま使える**
- **危険なのは「どちら回りか」ではなく、θ・α・uの3者が互いに整合しているか。** αだけ反転すると実効Kが`[−1.00, +12.81, −0.561, +0.734]`となり**38msで転倒**する
- 「最悪こちらで定義し直してもいい」とのこと

#### `src/SignCalibration/` を新規作成

メンバーBの提案手順をそのままコード化した。**ビルド0警告・0エラー、既存テスト88/88合格。**

```
dotnet run --project src/SignCalibration -- COM4 COM5
```

- **測定1（s_theta）**：ぶら下げたまま t_ff=+0.2N·m（静止摩擦0.147をわずかに超える最小限）を300ms流し、モータ報告位置が増える向きでs_thetaを決める
- **測定2（s_alpha）**：同じく t_ff=+0.3N·m×50msのパルスを流し、カウントの増減でs_alphaを決める。モデル予測は「u=+1N·mのとき θ̈=+454, α̈=+557 rad/s²」でαは増加するはず
- 安全策：開始角から**±20°**を超えたら即打ち切り（机のヘリは±45°）。各測定後トルク0で減速させてから失能

#### ★測定1の結果：s_theta = +1（確定）

```
開始角（生のモータ位置）: -0.431 rad（-24.7°）
θ（生）: -24.69° → -11.81°  (Δ+12.87°)
→ s_theta = +1
```

**このプロジェクトで初めてモータに非ゼロトルクを送った操作。** Δ+12.87°と明確に動いており、判定は信頼できる。

#### 測定2は未確定（想定通り）

印刷のためモジュールを外しており（結束バンドも切断済み）、アームに固定できない状態で実行したため**Δ0カウントで判定不能**。これはエラーではなく、**機械的に繋がっていないと測れない測定**なので当然の結果。

固定なしで先に済ませる案として`--watch-theta`/`--watch-alpha`という**トルクを送らない監視専用モード**も追加した（ビルド確認済み）。ただし、

- +θ方向（＝+e_t方向）と+α方向は**回る軸そのものが違う**（e_t、e_r、e_zの関係を理解した上で手で再現する必要がある）
- モジュールを最終的な向き（窪み面下向き・エンコーダ側外向き）で正確に保持できるかに精度が左右される

という理由から、**メンバーAの判断で「土台ができてから自動測定でやる」ことにした。** 監視モードはコードとして残してあるが、当面は使わない。

#### 16:00、退室

- rail 2個目を**稼働させたまま退室**（残り1時間4分）
- **予定を遅らせないため、8/25(火)を作業日に追加。やることはbaseの印刷のみ**
- 8/25は研究室の方Cが不在だが、7号館2階は普段から作業している場所で、**プリンタも自由に使ってよいとのことなので入室・操作に問題はない**
- 15:14にWrikeへ進捗報告を送信

### 8/25（火）：baseの印刷、ねじの寸法検討（メンバーA単独）

**この日のタスクはbaseの印刷のみ。新しい日付フォルダは作らず、`8月24日分/`をそのまま使っている。**

#### 印刷

- **rail 2個目は無事完了していた**（8/24から回しっぱなしにしたもの）
- **baseの印刷を開始。11:32時点で残り3時間45分＝完了予定15:17ごろ**。16:00まで約43分の余裕
- 材料交換が挟まった場合に手間取らないよう、**待ち時間のうちに交換手順の動画を見る／Eigerの通知を有効にする／交換用フィラメントを手元に出しておく**ことを準備事項とした

#### ★ねじの寸法を詰め直した（この日の主な成果）

**きっかけは「新板と旧板で厚みが違うならねじの話が全部変わる」というメンバーAの指摘。** 実際その通りだった。

| | 板厚 | ＋スペーサ4mm | 噛み合い |
|---|---|---|---|
| 旧板 | 6mm | 10mm | 4.7mm |
| **新板** | **8mm** | **12mm** | **2.7mm** |

- 新板が8mmであることは、スクリプトの`base_t=8.0`と、実際に印刷するSTLの全高16.30mm（＝8＋パッド3.3＋ペグ5.0）の**両方から確認**
- 手持ちのねじは**M3なべ・全長16.7mm・頭2.0mm＝軸長14.7mm**（現物を実測）
- **結論：推奨はM3×16なべ（噛み合い4mm）。ただし8/25時点で手元に無い。無ければ手持ちの16.7mm品で組めるが、締めすぎないこと**

**★この日に出した誤りと訂正**

- **「M3×20なら確実」と一度案内したが誤り。** 軸長20mm − 板12mm ＝ 8mm突き出しとなり、深さ5mmの穴の底に当たって締まらない。正しくはM3×16
- **ねじ1本あたりの荷重を「5本で分担＝30N」と計算したが、パッド真下の1本を省く提案をした以上4本が正しく、約37N。** 結論（M3のせん断には十分小さい）は変わらない

#### パッド真下のM3スロットの問題

M3スロット6箇所の位置を計算したところ、**x=+13.50mm・y=0の1箇所だけがパッド（半径11.0〜33.2mm）の真下**に入ることが判明。パッド3.3mmに対しモジュール側の窪みは3.5mmで**余裕0.2mm**しかないため、なべ頭（2mm）が出るとモジュールが浮く。

**★未確認事項：この穴が「エンコーダのケーブルで元々使えない1箇所」と同じかどうか。同じなら5本、違うなら4本になる。**

#### メンバーBとの相談（8/25）

- **「レールは土台と一体化するべきだった」**（メンバーB）。**次に設計を触るときの改善点**。今回は分割のまま進める
- **「スペーサーはもともと保険なので、規格に合わないようなら無くしてもいい」**（メンバーB）
  → **検討した結果、外さない方がよいと判断した。** 外すと(1)今のねじが底突きする、(2)Ø86のベース板が固定ハウジングと1mmの隙間で対面し擦る危険がある（設計コメントに「擦れば摩擦が増えて制御が壊れる」と明記）。詳細は§7の5b-2

#### モータのねじ穴深さ5mmの出典を確認

デプスバーが壊れている可能性が出たため出典を確認した。**Damiao公式マニュアルp.4の寸法図（`6×M3↓5`）由来で、実測ではない。**
ただし**旧板構成で噛み合い4.7mmが問題なく締まっていた実績**があるため、実際の深さは少なくとも4.7mmあると間接的に裏付けられる。測り直す必要はない。

#### ★baseの印刷完了と組み立て（8/25 午後）

**baseの印刷が完了し、そのまま組み立てに入った。レール2枚を残して組み上がっている。**

##### ★モジュール側のM4ねじ穴が浅かった（この日最大の発見）

M4を締めてもモジュールがガタつき、ベース板との間に隙間が残る症状が出た。原因は**ねじの底突き**だった。

| 項目 | 値 |
|---|---|
| M4ねじ全長 | 19.1mm |
| 頭（設計時の想定値。未実測） | 4.1mm |
| 軸長 | 約15.0mm |
| ベース板 | 8.0mm |
| モジュールへ入ろうとする量 | **7.0mm** |
| **モジュール側の穴の深さ（8/25実測）** | **6.0mm** |
| 超過分＝隙間 | **約1.0mm** |

- 設計は「モジュール側へのねじ込みが7.3mm」を前提にしていた（`generate_qube_adapter.py`の`base_t=8.0`に付いたコメント）。**この7.3mmは実測ではなく見込みの値で、実際の穴は6.0mmしかなかった**
- **対処：M4の頭とベース板の間に平ワッシャー（0.8mm）を2枚挟む。** 進入量が7.0→5.4mmに減り、穴の底まで0.6mmの余裕ができる。噛み合い5.4mm（ねじ径の1.35倍）はM4として十分
- **1枚では足りない**（進入量6.2mmでまだ0.2mm底を突く）。**2枚でガタが消えることを実機で確認済み**
- スプリングワッシャーは潰れるので厚み稼ぎには使えない。**平座金（切れ込みのない平らなリング）を使うこと**
- ねじ頭がベース板下面に出る量が1.6mm増えるが、M4は回転軸から半径37.6mmでモータ本体（Ø57＝半径28.5mm）より外側なので干渉しない

**症状の読み方**：「ガタつくが向きはおおよそ固定されている」は、**ねじが底突きして締結力がまったく出ていない状態の典型**。向きを決めているのはパッドとペグなので、M4が効いていなくても向きだけは保たれる。次に似た症状が出たら、まずねじの底突きを疑うこと。

**確認方法**：板を外し、M4をモジュールの穴に直接ねじ込んで止まったところで、モジュール面からねじ頭の下面までを測る。これが使える深さ。

##### ★組み立ての順番を守ること（実地で判明）

**モジュールを先に付けるとM3スロットに手が届かない。** スロット6箇所とモジュールの位置関係は以下の通り。

| スロット位置 | モジュールとの関係 | ドライバーが入るか |
|---|---|---|
| (+13.50, 0) | **パッドの真下** | 不可（そもそも使えない） |
| (+6.75, ±11.69) | 円筒の真下。隙間は**6.3mm**しかない | **不可** |
| (−6.75, ±11.69) | モジュールの外 | 可 |
| (−13.50, 0) | モジュールの外 | 可 |

- モジュールを付けたままだと**3箇所しか締められない**。先にM3を締めれば、パッド真下の1箇所を除く**5箇所**が使える
- ねじ頭2mmに対し円筒下の隙間は6.3mmあるので、(+6.75, ±11.69)のねじ頭がモジュールに当たることはない
- 6.3mmの根拠：半径14mmの円筒が板に接しているので、y=11.69mmでの高さ ＝ 14 − √(14² − 11.69²) ＝ 6.3mm

##### 組み立ての到達点（8/25終了時点）

- スペーサ＋ベース板をM3×15でモータ出力フランジへ共締め → **完了**
- モジュールをパッド・ペグに載せ、**M4＋平ワッシャー2枚**で締結 → **完了。ガタなし**
- **残りはレール2枚のみ。8/26（水）に実施する**
- **パッド・ペグの削り合わせは不要だった。** 隙間の原因はM4の底突きであって、出っ張り側の印刷寸法には問題がなかった（一度パッドを削る方向で検討したが、実測により不要と判明）

### 8/26（水）：レール取り付け、測定2（s_alpha）確定、閉ループ倒立保持、★スイングアップ成功

**作業日は残り8/26（今日）・8/28・8/31のみ。**

#### 組み立て完了

- 側面レール2枚をM3×25＋スプリングワッシャーで取り付け、**機構部分が完成**
- メンバーCが、電源（モータのかさ上げ）とモータ側Misumi土台の固定治具を作成。**モータの結束バンド固定が不要になった**

#### ★測定2（s_alpha）完了：`s_alpha = +1`（確定）

組み立て完了後に`SignCalibration`を再実行。**測定1・測定2とも今回は失敗→パラメータ調整→成功、という経過をたどった。**

- **1回目・2回目とも失敗。** `ThetaTorqueNm=0.2N·m・ThetaPulseMs=300ms`で、開始角から20°を超えて安全装置が作動（Δ+19.87°、Δ+18.95°）。**組み立て直後は摩擦が以前より小さくなっており、同じパラメータでも動きすぎた**
  - さらに、測定1・測定2は「開始角」を1回だけ記録して共有しているため、測定1でアームが動いたまま測定2に入ると、その時点で角度の余裕をほぼ使い切ってしまい、測定2も連鎖的に失敗する（`SignCalibration/Program.cs`の`centerRad`が測定1・2で共通のため）
- **対処：`ThetaPulseMs`を300ms→150msに短縮**（`src/SignCalibration/Program.cs`）。加えて、測定2の前の「Enterで実行」待ちの間に、アームを手で開始角付近へ戻してから実行
- **3回目で両方成功。** `s_theta = +1`（Δ+8.15°、8/24の結果と一致）、**`s_alpha = +1`（Δ+31カウント≈+5.4°）**

これで座標系の符号が完全に確定した。

```
private const int SThetaSign = 1;   // θ_meas = SThetaSign × (モータ報告位置)
private const int SAlphaSign = 1;   // α_meas = SAlphaSign × (カウント×2π/2048) + オフセット
```

**両方+1（反転なし）なので、`PendulumTelemetry`が最初から使っていた角度計算式（θ=モータ位置−ゼロ点、α=カウント差分を度に変換）はそのまま正しく、符号変換の追加実装は不要だった。**

#### ★閉ループ制御プログラム`src/BalanceControl/`を新規作成

`PendulumTelemetry`は表示専用（トルク送信は常に0）だったが、これを初めて実際にモータへ送るプログラムに拡張した。

- `FurutaObserver.Step()`に`gainScale`引数を追加（既定1.0）。状態フィードバック`u_fb`だけに掛かる倍率で、摩擦補償`u_fric`には掛けない。「低いゲインから慎重に」試すためのつまみ
- ループ構造は「直前に実際に送ったトルクを`motor.TorqueCommand()`で送る→フィードバックを読む→`observer.Step()`に**実際に送った値**を渡して次のトルクを計算する」という、8/21に確立した「送ったつもりで予測しない」設計をそのまま踏襲
- 安全装置：アーム角が開始角から±40°、振子角が上向きから±60°を超えたら自動でトルク0→失能。Ctrl+Cでも同様
- ビルド0警告・0エラー、既存テスト88/88合格を確認済み

```
dotnet run --project src/BalanceControl -- COM4 COM5 <ゲイン倍率>
```

#### ★初の閉ループ試験（ゲイン倍率0.3）

**振子（α）は最後まで±2.8°以内で安定し、上向きをほぼ保持できていた。** 一方で**アーム角（θ）が `-0.1°→-0.9°→-2.1°→-9.4°→-16.7°→-31.4°` と加速度的に流れ、±40°の安全装置で自動停止**した。

原因はほぼ特定できている。

- `K`の1番目（アーム位置のゲイン、本来 `-1.00`）が0.3倍で`-0.30`まで弱まっていた
- 摩擦補償`u_fric`はゲイン倍率の対象外にしてあるため、動摩擦の正転0.109／逆転0.143という非対称性に由来する**一定の−0.13N·m前後の偏りが常にかかり続ける**
- 弱められた0.30の復元力ではこの一定の偏りに追いつけず、アームがじわじわ加速した
- **振子側のゲイン（K[1]=-12.8など）は0.3倍でも十分強く、最初から安定していた。弱すぎたのはアーム側だけ**

**次に試すこと：ゲイン倍率を1.0（フル、メンバーBが設計した本来のK）にして再試行。** 安全装置（±40°／±60°、Ctrl+C）は同じ体制のまま。

#### ゲイン倍率1.0でも同じ症状。摩擦補償を切ると悪化。K[0]の個別強化はさらに悪化

- **1.0（フル、素のK）でも、振子は安定するがアームがゆっくり流れて最終的に安全装置に達する**という同じ挙動を再現（数回試行、θドリフトの方向は毎回不定＝一定方向のバイアスではない）
- **仮説①「摩擦補償(u_fric)が一定の後押しになっている」を検証するため、`frictionScale`引数を追加して0（完全に切る）で試した。→ 悪化。** 0.5〜0.6秒というこれまでで最短の時間で発散し、しかも**今回は振子（α）も一緒に発散した**（それまでは振子だけは最後まで安定していた）。**実際の摩擦がむしろコントローラの弱さを隠す方向に働いていた**と判明し、仮説①は棄却
- **仮説②「θの復元力（K[0]）だけを個別に強めれば直る」を検証するため、`thetaGainBoost`引数を追加して3倍で試した。→ さらに悪化。** 2回試行し、2回目はほぼ即座（0.2秒未満）に安全装置まで到達。`u_fb`の符号がずれの拡大方向と一致しており、**LQRで設計された4要素のKを個別に手で弾ませると、行列全体の釣り合い（安定性の保証）そのものが崩れる**ことを実機で確認。K要素の手動個別調整はやってはいけないと判断し、この方針は放棄

#### ★★根本原因の特定と、LQR設計のBryson重みの見直し（この日最大の成果）

**メンバーAの判断で、`model/design_and_simulate.py`を実行してPython側から作り直す方針に切り替えた。**
「ここの調整はメンバーAさんの仕事」という方針を明確化（メンバーBは8/24〜28不在で今後も本件には不参加）。
CLAUDE.mdの「モデル導出とゲイン計算はPythonでオフラインに行ってよい」という例外規定に基づく。

- 環境に scipy・sympy・matplotlib が無かったため `pip install --user` で導入
- **まず変更前の設計をそのまま実行し、シミュレーション自体にすでにθドリフト（-17〜-21°）が出ていることを確認。** つまり実機で見えていた症状は、8/17時点の設計にもとから内在していた特性で、実装のバグではなかった
- 原因は`design_lqr()`の重み設定にあった。**Brysonの法則で `Q_ii = 1/許容偏差²` を作る際、旧設定は「θは±0.5rad、αは±0.05rad」＝Q_θθがQ_ααのわずか1/100しかなく、LQRが最初からθをほとんど気にしない設計になっていた**
- θの許容偏差を段階的に絞って感度解析（摩擦補償comp_scale 0〜1.1、アーム慣性J_r ×0.5〜3.0）とシミュレーションを実施

  | θ許容偏差 | K | θドリフト（6°初期傾き） | 最大トルク |
  |---|---|---|---|
  | 0.5rad（旧設計） | [-1.00, -12.46, -0.586, -0.683] | -17.2° | 1.33N·m |
  | 0.15rad | [-3.33, -15.55, -1.128, -1.081] | +3.9° | 1.67N·m |
  | **0.10rad（採用）** | **[-5.00, -17.73, -1.461, -1.325]** | **-4.5°** | **1.91N·m（T_MAX2.0に対し余裕僅か）** |

  0.10radより先に絞ると、大きい外乱でトルクが飽和し始めるためここで止めた
- **感度解析は0.10radでも全ケース成立**（摩擦補償を完全に切っても、アーム慣性が半分〜3倍にずれても転倒しない）
- `model/FurutaGains.cs`を再生成し、`csharp/src/DamiaoCan/FurutaGains.cs`へコピー（毎回必要な手順、§3.5参照）。ビルド0警告・0エラー、テスト88/88合格
- **実機再試験（0.10rad版、倍率はすべて1.0＝素のK）：振子は最後まで大きく崩れず、アームは−6〜−8°付近で少し粘ってから結局逃げる、という挙動に改善。まだ完全ではないが、0.15rad版よりは長く粘るようになった**

#### ★★アーム角の安全ガードを±40°→±140°に拡大

**「40°では制御の実力を見る前に打ち切ってしまっている」というメンバーAの指摘で変更。** `BalanceControl/Program.cs`の`ArmAngleLimitDeg`を140.0に変更（振子角の上限±60°は変更なし）。

- 変更前に、**「1回転はさせない（配線が引っ掛かる）」というこれまでの制約と矛盾しないか**を確認。メンバーCがケーブルを整理し、その範囲でも突っ張らないことを確認済みとのことで実施
- ±140°は振れ幅280°で1回転(360°)には達しないが、机の縁のクリアランスはメンバーCの新しい固定治具で従来の±45°から拡大している

#### ★★★実機で約30秒の連続保持に成功（この日の到達点）

安全ガード拡大後、0.10rad版のKで再試行したところ、**約30秒間（表示300行前後）、一度も安全ガードに達することなく制御が継続し、メンバーAが意図的にCtrl+Cで止めるまで動き続けた。**

- 途中、振子角±7°・アーム角−50°台に達するような大きな乱れが複数回入ったが、**そのたびに小さな振動へ回復している**（たまたま倒れなかったのではなく、実際に立て直す動きが繰り返し確認できる）
- **メンバーAが手で振子に触れて外乱を加えたところ、倒れる方向ではなく避ける方向に反応した**
- **何も乱さない状態では、小さく振動し続ける（リミットサイクル）。** シミュレーションが予測していた「1.3〜1.4°程度のリミットサイクル」と一致する挙動
- 振子・アームとも、机や周囲の物に接触する場面は無かった

**今日の目標だった「振り上げに進む前提としての維持」は達成したと判断してよい状態。**

#### ★頑健性の確認（複数回の試行を数字で比較できるよう改良）

「維持ができたのはまだ1回・小さい外乱だけ」というメンバーAの指摘で、本格的な頑健性確認に入る前に`BalanceControl`へ**保持時間・最大アーム角・最大振子角を終了時に自動集計する機能を追加**（実行のたびに全ログを貼らなくても比較できるように）。

##### ①再現性の確認（外乱なし、3回）

| 試行 | 保持時間 | 最大アーム角 | 最大振子角 | 終了方法 |
|---|---|---|---|---|
| 1回目 | 22.6秒 | 38.2° | 5.6° | Ctrl+C（意図的） |
| 2回目 | 32.8秒 | 15.1° | 2.5° | Ctrl+C（意図的） |
| 3回目 | 24.0秒 | 40.2° | 5.3° | Ctrl+C（意図的） |

**3回とも、安全ガードに達する前にメンバーAが自分で止めるまで崩れなかった。** たまたまではないことを確認できた。

- **アームが落ち着く場所は毎回違う**（−28〜−38°、+7〜+15°、−28〜−40°）。0°付近のこともあれば離れた場所のこともあるが、**どこであっても崩れずに済んでいる**。離した瞬間の条件によってどの限界サイクルに落ち着くかが変わる、非線形系でよくある性質と考えられる。実害なし

##### ★②の直前に発生：制御周期の突然の崩壊と激しい振動（→同日夕方に原因確定。この節の末尾を参照）

②（外乱を段階的に強くする）に入る前、**何も外乱を与えていない状態で、モータが自然に激しく振動し始める事象が発生。**

- 正常時（`obs更新Hz`約500〜600、最大dt約5ms）で約5秒経過後、**突然`obs更新Hz`が130前後まで低下、最大dtが17.8msまで悪化**（安定条件dt<13msを破る）
- 同時に`u_total`が**ほぼ毎サイクル±2.00N·m（飽和上限）を交互に叩く**バンバン振動に入り、θ̇・α̇も±10rad/s前後で符号反転を繰り返す
- 約7秒間この状態が続いたのち、一度持ち直して別のリミットサイクル（アーム−48〜−54°）に落ち着き、メンバーAがCtrl+Cで停止（保持時間13.6秒、安全ガードには未到達）
- **モータの状態を`--status`（新設。トルクを送らず温度・エラーコードだけ読む）で確認したところ、エラーコード0（正常）、ドライバ温度31℃・モータ内部温度29℃と完全に健全。** モータ側の過電流・過熱保護が働いたのではないと判明
- （この時点では原因未特定。CAN通信のノイズを疑っていたが**外れ**だった。**同日夕方に原因を特定している。この節の末尾を参照**）
- `src/SignCalibration/`に`--status`モードを追加（`dotnet run --project src/SignCalibration -- --status COM5`）。モータの位置・速度・トルク・両温度・エラーコードを1回読んで表示するだけの読み取り専用モード。今後、異常が疑われたときに毎回同じ手順で確認できるようにした

**この事象は安全ガード（±140°／±60°）の範囲内で収まったが、モータが飽和トルク付近で数秒間振動し続けたのは実機への負荷として軽くない。**

**→ 原因は同日夕方に特定・確定した。「§4 8/26夕方：揺れの調整と、振動現象の原因確定」を参照。**

##### ②外乱の強さを段階的に（実施・安全ガードで終了）

`--status`でモータの健全性を確認したうえで②を実施。**外乱を徐々に強くしていき、最終的に安全ガード（アーム角+141.0°、上限±140°）で自動停止した。** 保持時間15.5秒、最大アーム角137.8°、最大振子角41.8°。

- **序盤〜中盤は、かなり強い外乱にも回復している。** 特にアームが+69.0°まで振れた場面（振子−26.9°）から、−31〜−37°付近まできれいに戻ってきた実績あり
- **振子角は最後まで41.8°までしか達していない（上限60°の内側）。** つまり最終的に止まった直接の原因は「振子が倒れた」ことではなく、**強い外乱への応答でアームが大きく動く必要があり、その分の可動域（±140°）を使い切った**こと。振子の立て直し自体は最後まである程度機能していたとみられる
- 最後の外乱直前、θ̇が+21.4rad/s・α̇が−19.3rad/sに達した（これまでで最大級）。**メンバーAの申告では「壊さない程度に、それまでよりだいぶ強く」入れたとのこと**
- **今回は前述の制御周期崩壊（130Hz急落・7秒振動）は再発しなかった。** 最大dtは8.9msまで上昇したが13msの安定限界内で収まっており、前回とは別の、素直な「外乱が大きすぎて可動域を使い切った」失敗と判断できる

##### ③外乱の方向（簡易確認のみで十分と判断）

②の外乱ログを見返すと、**アームが正負両方向に大きく振れて、どちらも回復している場面がすでに含まれている**（+69°からの回復、その後の−方向の外乱からの回復）。摩擦の非対称性（正転0.109／逆転0.143）を踏まえても、③として改めて厳密な段階的テストをやり直す必要は薄いと判断。軽い確認（弱め・強めを各方向1回程度）に留めて、頑健性確認はここで区切ることとした。

**③実施結果：保持18.2秒、最終的に振子角−61.7°で安全ガード。** ただし途中でアームが−117.4°まで振れる場面から回復するなど、相当強い外乱にも耐えることを確認。方向による明確な差は見られなかった。

##### モータの動きの「かくかくした」揺れについて（メンバーAの観察・原因の説明）

何もしていない待機中、モータの動きが滑らかでなく、かくかくして見えることにメンバーAが気づいた。**これは静止摩擦によるスティックスリップとほぼ断定できる。** 平衡点付近で必要な制御トルクは静止摩擦（0.147N·m）よりずっと小さいため、①固着→②誤差蓄積→③静止摩擦を超えて滑る→④行き過ぎる→①に戻る、を繰り返す。8/12時点で「静止摩擦は『その場に留める』問題では味方に回る」と分かっていた話の実機での現れであり、**完全に静止することは原理的にできず、小さなリミットサイクルが最良の定常状態**（今回のKでのシミュレーション予測は1.3〜1.4°、実機はそれに近い数°）。バグではなく、対処不要と判断。

##### ⑤長時間の無外乱放置（実施・205秒保持）

**保持時間205.2秒（3分25秒）、最大アーム角66.5°、最大振子角8.8°。Ctrl+Cで意図的に終了、安全ガードには未到達。** 頑健性確認（①〜⑤）はこれで完了とし、スイングアップの実装に進むことにした。

##### 頑健性確認の総括

| 項目 | 結果 |
|---|---|
| ①再現性（外乱なし×3） | 全て安全ガード到達前にCtrl+Cで終了。22.6秒／32.8秒／24.0秒 |
| ②外乱を段階的に強く | 保持15.5秒。アーム+69°からの回復を確認したのち、より強い外乱でアーム角上限（+141.0°）に到達 |
| ③外乱の方向 | 保持18.2秒。アーム−117.4°からの回復を確認したのち、振子角上限（−61.7°）に到達。方向依存は見られず |
| ⑤長時間放置 | **保持205.2秒。Ctrl+Cで意図的終了、安全ガードには未到達** |
| （制御周期の突然の崩壊） | ②の前に1回発生。以降のテストでは再発せず。**原因は同日夕方に確定（他ウィンドウのクリック）** |

**今日の目標「振り上げに進む前提としての維持」は、頑健性の面でも十分に達成したと判断。**

### ★★★スイングアップ（振り上げ→キャッチ）の実装と成功

「維持」の頑健性確認が済んだあと、メンバーAの判断で同日中にスイングアップへ着手した。

#### 方式：エネルギー整形則

`model/furuta_model.py`と同じLagrangianの枠組みで、振子の力学的エネルギー
E(α,α̇) = ½·J_pivot·α̇² + m_p·g·l_p·cosα （J_pivot = J_p + m_p·l_p²、支点まわり）
を導出し、dE/dt = −m_p·l_p·a·α̇·cosα（aはアームの接線加速度）という関係から、
**a = k_e·(E−E_top)·sign(α̇·cosα)** とすればエネルギーが単調に増えることを導いた（メンバーAが手計算、詳細は`src/SwingUp/Program.cs`冒頭のコメントに導出込みで記録）。実装ではa→トルクの厳密な変換はせず、`SwingGain·(E−E_top)·sign(...)`を直接トルク指令として使う経験的な形にした。

#### 開始条件：振子が真下で静止するのを自動検出

メンバーAの指摘（8/26、維持の議論中）を反映し、**「真上に持っていってEnter」ではなく、振子が自然に真下で静止するのを自動検出してから校正する**方式にした。1秒間の振れ幅が2°未満になったら静止と判定。人間の手癖による初期条件のばらつきが無くなった。

#### つまずいた点1：アームの「押しっぱなし」による暴走（40°→即座に安全ガード）

初回試行、振り上げ開始0.4秒でアーム角±140°の安全ガードに到達。**エネルギー整形則は振子だけを見ており、アーム自身には位置を戻す力が一切無かった。** 振子が真下から水平に近づくまでの約1/4周期の間、力の向きが変わらず、軽いアーム（J_r=0.00213）が加速度的に振り切れた。

- 1回目の対処（常時弱いバネKp=1.0）→ 暴走は止まったが、今度は**振子の振れ幅が11.6秒間まったく育たなくなった**。バネがエネルギー整形則のポンピング動作自体を打ち消していたと判断
- 2回目の対処（**閾値方式**）：±30°以内は常時ごく弱い減衰のみ、それを超えた分にだけ強いバネ（Kp=5.0）を掛ける方式に変更 → **振子の振れ幅が正常に育ち、約5.8秒で上向き付近（キャッチ角度±25°以内）に到達**

#### つまずいた点2：キャッチ切り替え直後の飽和トルクによる再暴走

振り上げ自体が成功した初回、キャッチに切り替えた瞬間に`u_total`がいきなり−2.00（飽和）になり、0.3秒でアーム角±140°の安全ガードに到達して失敗した。

**原因：振り上げ中に使っていた「巻き戻さないα」をそのままLQRのオブザーバに渡していた。** 振り上げでは振子が何周も振れるため、内部的なα（生の値）は数百度分蓄積している。表示上の角度（±180°に巻き戻した値）は+23.9°でも、オブザーバに渡していた生の値はそれとかけ離れた大きな数値になっており、LQRが「αが激しくズレている」と誤認して即座に飽和トルクを出していた。

**対処：キャッチフェーズでオブザーバに渡す直前だけ、±180°に巻き戻した値に変換する**（`alphaWrapped * π/180`）。振り上げフェーズ自体の物理計算（cos/sinを使うため巻き戻し不要）はそのまま。

#### ★★★成功（最終試行）

**振り上げ約5.8秒 → キャッチ → そのまま15秒以上安定保持、メンバーAが意図的にCtrl+Cで終了（経過時間21.2秒、最大アーム角43.0°）。** キャッチ直後に一瞬+2.00の飽和が出たが、前回と違い数コマで収束し、以降は±1〜2°のリミットサイクルに収まった。途中、振子7.7°・アーム−33°まで乱れる場面があったが、②③で確認した頑健性どおり回復している。

**真下で静止した状態から、人手を介さず自動で振り上げ・キャッチ・維持まで到達した。9/16の発表に向けた最重要マイルストーンの一つ。**

`src/SwingUp/`（新規）
```
dotnet run --project src/SwingUp -- COM4 COM5
dotnet run --project src/SwingUp -- COM4 COM5 <SwingGain> <振り上げ中のトルク上限N·m> <キャッチ角度deg>
```
既定値：SwingGain=15.0、振り上げ中のトルク上限=0.8N·m、キャッチ角度=±25°。ビルド0警告・0エラー、テスト88/88合格。

**★8/27追記：SwingGain=15.0は小さすぎることが判明した（真上付近で摩擦残差に負ける）。30にすべき。既定値はまだ変えていないので、当面は引数で `... COM4 COM5 30` と渡すこと。詳細は§4の「8/27 午後」。**

#### ★2回目も成功（再現性を確認）

動画記録も兼ねてもう一度実行し、**2回連続で成功**した。

| | 振り上げ時間 | 経過時間 | 最大アーム角 | 終了方法 |
|---|---|---|---|---|
| 1回目 | 約5.8秒 | 21.2秒 | 43.0° | Ctrl+C（意図的） |
| 2回目 | **約1.5秒** | 15.5秒 | 84.1° | Ctrl+C（意図的） |

- **どちらも安全ガードには一度も達していない**
- **振り上げに要する時間は毎回ばらつく**（5.8秒 → 1.5秒）。真下で静止した状態から始めても、ポンピングの位相の噛み合い方で変わるとみられる
- **保持中の揺れ方も回によって違う。** 1回目は数コマで±1〜2°の細かいリミットサイクルに落ち着いたが、2回目はアームが40〜84°の範囲で何度か大きめに揺れる場面が繰り返し出た。ただし**毎回きちんと戻ってきており、安全ガードには一切触れていない**。②③の頑健性確認で見た「毎回ちょっとずつ違う場所に落ち着く」性質の延長線上にある
- **2回目を動画で記録**（`IMG_0300.MOV`、約49MB、メンバーAのDownloadsフォルダ）。※動画ファイルはAI側では内容を確認できないため、判断はメンバーAが実物を見て行っている

#### ★★動作確認済みコードのスナップショットを保存

**これ以降パラメータ調整を続けるにあたり、「実機で成功したことが確認できている状態」を先に退避した。**

`8月26日分/動作確認済みコード_20260826/`
- `SwingUp_Program.cs` / `BalanceControl_Program.cs` / `FurutaObserver.cs` / `FurutaGains.cs`
- `README.md` … 実績・そのときの全パラメータ・復帰手順を記載

**調整で挙動が悪化したら、README.mdの表に従って元の場所へ上書きコピーし`dotnet build`すれば必ず動く状態に戻せる。**

#### 予定の変更（8/26時点の見込み）

スイングアップまで到達したため、**8/28（金）を実機作業の最終調整日、8/31（月）以降をポスター制作に充てる方針で確定**（8/26夕方、メンバーAの判断）。8/28が早く終われば、その日のうちにポスター制作へ移る。8/28にやることは§7を参照。

### ★8/26夕方：揺れの調整（成功）と、振動現象の原因確定

#### 1. 保持中の「くねくね」を、Brysonのθ̇重みで大幅に改善

スイングアップ成功後も、**保持中にアームが40〜84°の範囲で揺れ続けて静止しない**問題が残っていた。

**着目点**：θもαもズレ自体は小さい（±1〜2°）。ズレたまま止まっているのではなく、振動が止まらない。つまり**位置の重みではなく減衰が足りない**と判断し、θ̇の許容偏差を絞った。

`model/design_and_simulate.py`

    max_dev = [0.10, 0.05, 3.0, 3.0]   → [0.10, 0.05, 1.5, 3.0]

Q_θ̇θ̇ が 1/3.0² から 1/1.5² へ、つまり4倍になる。

| | 変更前 | 変更後 |
|---|---|---|
| K | [−5.00, −17.73, −1.461, −1.325] | **[−5.00, −18.87, −1.534, −1.448]** |
| 最速閉ループ極 | — | −179.7 rad/s（≈29Hz） |
| **保持中のアーム揺れ幅** | **40〜84°でうろつく** | **−6°〜+3°（幅9°）** |
| 保持中の振子揺れ幅 | ±1〜2° | **±1°程度** |

**アームのうろつきがほぼ消えた。** スイングアップから連続で114.7秒の保持を確認（後述の振動を2回挟んだが、2回とも自力で復帰し、元の小さいリミットサイクルに戻っている）。

**注意（シミュレーション上のトレードオフ）**：初期傾き6°・10°のケースで最大トルクが2.000 N·m（飽和）に達するようになった（変更前は1.911 N·mで余裕があった）。全ケース「成立」は維持しているが、**大きい外乱に対しては変更前より飽和しやすい可能性がある。** 変更後に大きな外乱テストは未実施。

**Kの4要素は必ずこの重み経由でまとめて再設計すること**（個別に手でいじると悪化するのは8/26午前に実機で確認済み）。

#### 2. ★制御周期の崩壊＝「他のウィンドウをクリックすると起きる」で確定

午前に1度起きて原因未特定だった現象が再発したため、切り分けた。

**確定手順**：
1. 2分弱まったく触らずに放置 → **一度も発生しない**
2. 別のウィンドウをクリック → **その瞬間に発生**
3. もう一度クリック → **再び発生（2/2で再現）**

**原因**：Windows 11は、**プロセスがフォアグラウンドでなくなると電力管理としてタイマ分解能の要求（`timeBeginPeriod(1)`）を無視する。** 分解能が既定の約15.6msに戻り、制御ループが回らなくなる。

| | 正常時 | 崩壊時 |
|---|---|---|
| obs更新Hz | 約575 | **約130** |
| 最大dt | 5.6ms | **15.7 → 19.1ms** |
| u_total | ±0.2 N·m以下 | **±2.00 N·m（飽和）のバンバン振動** |

**dtが跳ねた瞬間の値が15.7msで、Windows既定の15.625msと一致する**のが決定的な証拠。

**なぜ発振するか**：新しいKの最速閉ループ極は −179.7 rad/s ≈ 29 Hz。制御が130Hz・実dt 19msになると、制御帯域に対してサンプリングが足りず、飽和トルクを往復するバンバン動作になる。**制御則の問題ではなく、制御則を回す速さの問題。**

午前の1件（obs更新Hz 130、最大dt 17.8ms、u_total ±2.0バンバン、約7秒で自然復帰）も**まったく同じsignature**であり、同一原因と確定した。CAN通信のノイズを疑っていたのは外れ。

##### 対策（未実装。次に実機を触るときの候補）

1. `SetProcessInformation` で `PROCESS_POWER_THROTTLING_IGNORE_TIMER_RESOLUTION` を設定し、フォアグラウンドでなくてもタイマ分解能を維持する
2. **dtが閾値（例：8ms）を超えたフレームは制御更新をスキップして前回トルクを保持する。** タイマが外れても発振しない保険になるので、1より重要かもしれない

**未対策のまま運用する場合の回避策：実行中はコマンドプロンプト以外のウィンドウを絶対にクリックしない。** 9/16の実演でも同じ注意が必要。

**発表向けの価値**：「原因不明の振動 → 切り分けで再現条件を特定 → 制御帯域とサンプリング周波数の関係で説明できた」という流れは、そのままポスターの1トピックになる。

### ★★8/26 夜：スイングアップが再現しなくなった。振子角の測定が実際とずれている（未解決・最優先）

**この節が8/27朝に最初に読むべき内容。** 揺れの調整までは順調だったが、そのあと状況が変わった。

#### 経過1：改善版Kでスイングアップが1/5しか成功しなくなった

θ̇の重みを変えた直後は2回とも良いキャッチができていたが、その後5回連続で回したところ**成功1回・失敗4回**。失敗は**すべてキャッチに切り替えた直後の1〜2コマ**で起きている。

| 回 | 切替時の振子角 | キャッチ1コマ目のu_total | 結末 |
|---|---|---|---|
| 1 | +23.0° | −1.13 → −1.87 | アーム角ガード −143.4° |
| 2 | −24.8° | **+1.14 → +0.12** | **成功**（9.0秒、最大アーム角44.3°） |
| 3 | +24.1° | −1.83 → −2.00 | アーム角ガード −140.9° |
| 4 | −24.8° | +1.67 | アーム角ガード +141.9° |
| 5 | +25.0° | +2.00 | 振子角ガード +61.9° |

**成功と失敗の差は紙一重で、Kの違いではない。** 旧Kでも2回成功しているだけで、試行回数が少なかった。**もともと成功率5割程度の博打だったところに、最初の数回がたまたま当たっていた**とみるのが自然。

#### 原因の見立て：キャッチ判定が振子の角度しか見ていない

`src/SwingUp/Program.cs` のキャッチ判定は

    if (Math.Abs(alphaWrapped) < catchAngleDeg)   // 既定 25.0

の1行だけで、**α̇（振子の速度）を一切見ていない。** 振子が速く通過している瞬間に捕まえても切り替わってしまう。

さらに、**LQRの設計上のα許容偏差は0.05 rad ＝ 2.9°**。そこへ**±25°**、つまり約8倍の状態で飛び込ませている。線形近似が成り立つ範囲の外。

**実測での裏付け**：`PendulumTelemetry`（トルク0の読み取り専用）で振子角−40°のとき、`u_fb`が**−43 N·m**と表示された（飽和して−2.00に切られる）。大きい角度でLQRの計算値が桁違いになることが実機で確認できた。**キャッチ角度を狭める根拠としてそのまま使える。**

**対策案（8/27に実装）**
1. **キャッチ判定に「|α̇|が閾値以下」の条件を追加する**（本命）
2. キャッチ角度を±25°から±15°程度に狭める
3. オブザーバの初期状態：**振り上げ中はオブザーバが動いていない**（`obs更新Hz`が0）。キャッチ時に内部状態がゼロから始まるため立ち上がりが暴れる。測定値で初期化する

#### ★経過2：振子角の測定が実物とずれる（こちらが本題）

Kを2回連続成功時のスナップショットへ戻して撮影しようとしたところ、**今までと違う挙動になった。**

- **アームが±40°も振れているのに、振子角が180°（真下）からほとんど動かない。** 健全ならアームが振れた瞬間から振子は振れ始める
- そのあと振子角が **180° → 25° へ、9秒かけて一方向に単調に減り続けた。** 行ったり来たりが一度も無い。成功時のログは `+160 → +144 → −132 → −88` と符号が振れる
- **メンバーAの目視：実物の振子はまだ上に行っていないのに、プログラムは「+25°＝真上付近」と判断してキャッチに切り替え、アームを+101°まで全力で振った**

**自由な振子が、揺れずに真下から真上へ9秒かけてじりじり登る、という運動は物理的にありえない。** つまり**表示されているαが実物と一致していない。**

#### 切り分け：読み取り単体は正常（手でゆっくり動かす範囲では）

`PendulumTelemetry`（トルク指令が常に0でモータを動かさない）で確認。

```
dotnet run --project src/PendulumTelemetry -- COM4 COM5
```

- アーム角は終始+0.0（モータは動いていない。正常）
- **振子角は手の動きどおりに追従した**（0°付近から−40°へ素直に変化）
- **読み取り系そのものは生きている**

**ただしこの試験は「ゆっくりの動き」しか見ていない。**

#### ★8/27に最初にやる試験（未実施）／★★診断を8/26夜に修正

**★修正（メンバーBの指摘）：第一候補は「速い動きでのカウント取りこぼし」ではなく「A相／B相の接触不良（間欠断線）」。**

**速度説は数字で持たない。** 振子エンコーダはE8T-512（512ライン、4逓倍で2048カウント/回転）。振り上げ中の振子は最大でもα̇≈10 rad/s ＝ 約1.6回転/秒なので、**カウント発生レートは3〜4 kHz**。TIM1のハードウェアエンコーダモードはMHz級まで扱えるので、この程度で取りこぼすことは考えにくい。シリアル（921600 baud）でフレームが落ちる可能性はあるが、`PendulumEncoderReader`が読んでいるのは**積算カウント**なので、フレームが落ちても値が古くなるだけでカウント自体は失われない。飛びは出ても片方向の単調ドリフトにはならない。

**接触不良なら、あのログがそのまま説明できる。**

- **片相が完全に切れている間**：エッジが来ないのでカウントが凍る → **アームが±40°振れても振子角が180°から動かない**（ログ前半）
- **片相が固定レベルで張り付いた状態**：TIM1のエンコーダモードは**もう一方の相のレベルで計数方向を決める**。B相が張り付くと、A相のエッジが来るたびに**常に同じ向きにしか数えない**
- つまり**振子が行ったり来たりしてもカウントは一方向に増え続ける** → **180°→25°の単調ドリフト**

**取りこぼし説では「行ったり来たりが一度も出ていない」ことを説明できない。** 振子が振れている以上、αも振れて見えるはず。**片相が死ぬと振動そのものが消える。** ログに合うのはこちら。

**手動テストで正常に見えたこととも矛盾しない。** 読み取り専用テストでは値が `+6.7 → +5.6 → +3.9 → +1.8 → −0.7 → −3.9 → −5.8` と**両方向に動いていた**＝あのときは両相とも生きていた。**間欠不良なら「調子がいいときは正常」で当然。**

**時系列も合う。** 直前に安全ガード到達を繰り返し、アームを±140°まで全力で何度も叩きつけていた。**振動と衝撃は、限界にあるコネクタを間欠不良にする典型的なきっかけ。**

##### 手順（すべて`PendulumTelemetry`で見る。トルク指令0なのでモータは動かない）

```
dotnet run --project src/PendulumTelemetry -- COM4 COM5
```

**A. 接触不良の確認（これを最初に）**

1. **振子を止めたまま、コネクタとケーブルを軽く揺すって、振子角の表示が動くか**
   → **動けば接触不良で即確定**
2. **振子をゆっくり左右に振って、両方向に数えるか**
   → **一方向にしか増えないなら片相が死んでいる**
3. コネクタの抜き差し、はんだ付け部の確認

**該当箇所**：エンコーダ E8T-512 → NUCLEO-G474RE
- **A相＝白 → D7（PA8, TIM1_CH1）**
- **B相＝緑 → D8（PA9, TIM1_CH2）**
- 詳細な配線表は§3を参照

**B. Aで異常が出なかった場合のみ：積算の整合を見る**

1. 振子を**真下でぶら下げて静止**させ、そのときの振子角を控える
2. **手でゆっくり1回転**させて真下に戻す → 控えた値に戻るか
3. **手で勢いよく弾いて数回転**させ、自然に真下で止まるまで待つ → また控えた値に戻るか

- **2は合うが3で合わない** → 速度依存の取りこぼし（上のとおり考えにくいが、その場合は配線の引き回し・シールドを疑う）
- **3も合う** → モータが強いトルクを出しているときだけ起きることになる。**モータの大電流によるノイズ**が濃厚。エンコーダ線とモータ電源線の引き回しを離す方向

**なお8/21に「TIM1ハードウェアエンコーダモードならモータ稼働時でも誤カウントが発生しない」ことを実測で確認済み**（§4 8/21）。**そのときは問題が出ていなかったのだから、8/26に何かが変わったということ。** 配線・コネクタの物理的な状態変化を最初に疑う根拠になる。

**この件が片付くまで、パラメータ調整には意味がない。** 誤った角度に基づいて毎回フルトルクでアームを安全ガードまで叩きつけることになり、借用品のQUBEモジュールとモータへの負荷としても良くない。

#### いま実機に入っているコード

**2回連続成功時のスナップショットに戻してある。** スナップショットとの差分は`FurutaGains.cs`の1ファイルだけだった（`SwingUp/Program.cs`・`BalanceControl/Program.cs`・`FurutaObserver.cs`は同一）。

| | 場所 | K |
|---|---|---|
| **いま入っている** | `src/DamiaoCan/FurutaGains.cs` | [−5.00, −17.73, −1.461, −1.325]（θ̇=3.0版） |
| 揺れ改善版を退避 | `8月26日分/FurutaGains_θdot1.5版_20260826夕.cs` | [−5.00, −18.87, −1.534, −1.448]（θ̇=1.5版） |

**揺れの改善（アーム40〜84°→約9°）自体は本物なので、測定の問題が片付いたら改善版に戻すこと。** 上書きコピーして`dotnet build`するだけ。

#### 予定変更

**8/27（木）を作業日に追加。** 実機の調整を8/28（金）までに終え、8/31（月）以降をポスター制作に充てる方針は維持。

### ★8/27（木）：接触不良の修理と、ハード側の疑いを全て潰した日

**結論を先に：ハード側（配線・エンコーダ・摩擦）はすべて正常と確認できた。振り上げが頭打ちになる現象は残っているが、原因は機械でも測定でもない。**

#### 0. 8/26夜にメンバーBが代理で作業（4極ジャックのはんだ付け）

メンバーAの不在中にメンバーBが来て状況を確認し、**4極ジャックの差込口をはんだでしっかり止め直した。**

あわせて**メンバーBの指摘で診断を修正した。詳細は§4「★★8/26 夜」に記載したとおり、第一候補は「速い動きでのカウント取りこぼし」ではなく「A相／B相の接触不良（間欠断線）」。** 速度説は数字で持たない（E8T-512の2048カウント/回転、振子は最大でも約1.6回転/秒＝3〜4kHz。TIM1のハードウェアエンコーダモードはMHz級まで扱える）。

#### 1. 配線のつなぎ直し

はんだ付けのために外していたので、§3の配線表どおりに戻した。

| 振子モジュールのプラグ | 色 | Nucleo側 |
|---|---|---|
| 先端（5V） | 赤 | `5V` |
| リング1（**A相**） | 白 | **`D7`**（PA8＝TIM1_CH1） |
| リング2（**B相**） | 緑 | **`D8`**（PA9＝TIM1_CH2） |
| 根本（GND） | 黒 | `GND` |

**`D11`・`D12`には絶対に繋がない**（5Vトレラントではない）。**D7とD8は隣同士**、D9はもう1つ先（8/19まではA相をD9に挿していた）。

#### 2. ★エンコーダの読み取りは正常に戻った

`dotnet run --project src/PendulumTelemetry -- COM4 COM5`（トルク指令0、モータは動かない）で確認。

**昨夜の壊れたログとの決定的な違いが2つ出た。**

- **反転が正しく検出できている**：`−1.2 → −0.9 → −0.2`と戻ってから再び減る、という往復が何度も出る。昨夜は一方向にしか動かなかった
- **±180°をまたぐラップアラウンドが正常**：`+179.8 → −177.5 → −176.7`と連続して切り替わり、飛びや固着がない

さらに後の試験で、**アームと振子を手で同時に激しく揺すった状態でも、振子角は一度も固まらず正しく反転した。** 接触不良・取りこぼしの疑いはこれで晴れたと判断する。**はんだ付けの修理は機能している。**

##### ※PendulumTelemetryを手で動かすときの注意（次に使う人へ）

**手で自由に動かしていると、`推定α̇`・`推定θ̇`・`u_fb`・`u_total`の列が異常な値になる**（α̇が100rad/s超、u_totalが±500超など）。バグではない。**このプログラムはトルクを実際には送っていないのに、内部のオブザーバは「自分が計算したu_totalが実際にモータへ送られている」という前提でモデルを回している。** 手で動かしている状況とその前提が食い違うため、推定値だけが破綻する。**生の`振子角`・`アーム角`の2列だけを見ること。**

#### 3. ★摩擦は増えていない（アーム側・振子側とも実測）

##### `--mode ab`（モータは動かない）

**注意：FrictionTestだけポート指定の書式が他と違う。`--port`フラグが必要。**

```
dotnet run --project src/FrictionTest -- --mode ab --port COM5
dotnet run --project src/FrictionTest -- --mode breakaway --port COM5
```

結果：**「使能＋トルク0」の方が「失能」より明らかに回しやすかった。**

**8/6の逆駆動テストでは「失能時と使能時で感触に差がなく、寄生トルクなし」と記録されており、今回は逆の結果。** ただし**「回しにくくなる」のではなく「回しやすくなる」方向**なので、異常とは考えにくい。失能（無通電）だとモータ内部のコギングトルクがそのまま感じられるが、使能してトルク0を指令すると制御ループがそれを打ち消す方向に働くことがある。**むしろ制御が効いている側の兆候。** 事実として記録は残すが、今回の不具合の原因とは考えていない。

##### `--mode breakaway`（静止摩擦の実測、モータが回る）

| | 試行1 | 試行2 | 試行3 | 平均 |
|---|---|---|---|---|
| 正転 | 0.162 | 0.110 | 0.141 | **0.138 N·m** |
| 逆転 | 0.173 | 0.182 | 0.159 | **0.171 N·m** |

**静止摩擦 τ_c ≒ 0.154 N·m。過去の記録値0.147 N·mとほぼ同じで、増加していない。**

##### 振子側の自由振動（振子だけを離して放置）

**1回離しただけで約48秒間揺れ続けた。** 止めた時点でも振幅が±20〜25°残っていた。**減衰がかなり小さい＝振子側の軸受けの摩擦も低く良好。** 渋くなっていれば数秒〜十数秒で振幅が落ちるはずなので、この仮説も外れた。

#### 4. ★★残った現象：振り上げが「頭打ち」になる

改善版K（θ̇=1.5版）に戻してビルドし直したうえでスイングアップを実行したところ、**振り上がらずに37.8秒経過して終了。**

- `u_swing`と振子角の推移が**370行ほどにわたってほぼ完全に同じパターンで反復**（`+0.67 → +0.21 → −0.20 → −0.93`という並びが何十回も出る）
- **アーム角がその間ずっと−45°〜+43°の範囲に収まっている**（`最大アーム角 45.7°`）。成功時は楽に±80°以上振れる
- **振子角も一度も70°より上に来ない**＝真上に対して半分も上がっていない

**「たまたま抜け出せずにいる途中」ではなく、その振幅で安定してしまう均衡点に落ち着いている**ように見える。

**外れた仮説（この日つぶしたもの）**

| 仮説 | 結果 |
|---|---|
| ケーブルの引っかかり（はんだ付けで取り回しが変わった？） | 手で±45°回して確認、引っかかりなし |
| アーム軸の摩擦増加 | 実測0.154 N·m、過去とほぼ同じ |
| 振子軸の摩擦増加 | 自由振動48秒、むしろ摩擦は低い |
| エンコーダの読み取り不良 | 手で激しく動かしても正常に反転・追従 |
| コードが変わった | **`diff`で確認済み。`SwingUp/Program.cs`・`BalanceControl/Program.cs`・`FurutaObserver.cs`はスナップショットと完全一致。** 8/26夕方以降ソースは一切変えていない |

#### 5. ★成功した（同じコード・同じ設定のまま）

その後もう一度実行したところ、**あっさり成功した。**

| | 値 |
|---|---|
| 経過時間 | 18.8秒（Ctrl+Cで意図的終了） |
| 最大アーム角 | 43.2°（安全ガード±140°に未到達） |
| 保持中のアームの揺れ | **−5.6°〜+2.1°**（8/26夕方の改善版と同等の質） |
| 保持中の振子の揺れ | ±1.5°程度 |

**ハードは正常、コードも不変、それでも失敗と成功が混ざる。** これは**初期条件に敏感な系で、抜け出せる位相と詰まる位相がある**という理解で矛盾なく説明がつく。過去の成功例でも振り上げ時間が1.5〜5.8秒とばらついていたのと同じ性質の延長線上。8/27は運悪く「詰まる位相」を何度も引いていた。

#### 6. 8/28への申し送り

**エネルギーを注ぐ力（`SwingGain=15.0`）と、暴走を防ぐアームの戻す力（±30°超で`ArmHoldKpOutside=5.0`）の釣り合いが、意図せず「ある振幅で頭打ちになる均衡点」を作っている可能性が高い。**

**→ 8/27午後に原因を特定した。均衡点ではなく、単純に SwingGain の押す力が真上付近で摩擦残差に負けていた。次節を参照。**

**8/28に予定しているキャッチ条件の改善（α̇の条件を足す、キャッチ角度を±25°から狭める）は、キャッチ失敗型には効くが、この頭打ち型には効かない。** 頭打ちを減らしたいなら、アームの戻す力の設計（閾値30°、Kp=5.0）を見直す必要がある。**両方を8/28の課題として扱うこと。**

### ★★8/27 午後：試行を53回積み、SwingGain不足が本質だと判明

**この日の午後は「同じコードで結果が正反対に振れる」現象を、試行回数を積んで潰していった。結論はSwingGainが小さすぎたこと。**

#### 1. 試行結果の自動記録を実装（`src/SwingUp/trial_log.csv`）

何度も試すなら記録を残した方がいい、というメンバーAの提案で実装。**プログラム終了時に1行追記される。**

```
日時, 結果, 振り上げ秒, 経過秒, 最大アーム角deg, 最大振子角deg, 中断理由
```

**結果は自動分類される。**

| 分類 | 条件 |
|---|---|
| **成功** | キャッチへ切り替わり、その後は安全ガードに掛からず終了（Ctrl+C） |
| **キャッチ失敗** | キャッチへ切り替わった後に安全ガード到達 |
| **頭打ち** | そもそもキャッチへ切り替わらずタイムアウト／中断 |

判定は `caught`（キャッチ判定を一度でも通ったか）と `abortReason` の組み合わせだけで行う。ループ内では何もせず、終了後に1回書くだけなので制御周期に影響しない。

**あわせて、起動時に「コード更新履歴」を表示するようにした**（メンバーAの要望）。`Program.cs` 冒頭の `CodeChangeLog` 配列に、変更するたび先頭へ1行足す。**日付だけでなく時刻も入れること**（trial_log.csv のタイムスタンプと突き合わせるため）。
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

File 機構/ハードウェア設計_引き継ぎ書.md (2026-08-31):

# ハードウェア設計 引き継ぎ書

**回転型倒立振子（Furuta pendulum）の機構部設計**

この文書だけで作業に入れるように書いてある。制御ソフト側の詳細は
[`../倒立振子_ロードマップ.md`](../倒立振子_ロードマップ.md) と
[`../CLAUDE.md`](../CLAUDE.md) にあるが、機構設計に必要な情報はすべてここに再掲した。

- 作成日: 2026/08/12
- 締切: 2026/08/17（Day 4）に機構が組み上がっている必要がある
- **やり取りは日本語で行うこと**

---

## 1. 何を作るのか

Damiao **DM-J4310-2EC V1.1** をアクチュエータ、Quanser **QUBE-Servo 2 の回転振子モジュール**を
振子部として、回転型倒立振子を作る。QUBE 本体は無く、振子モジュールだけがある。
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

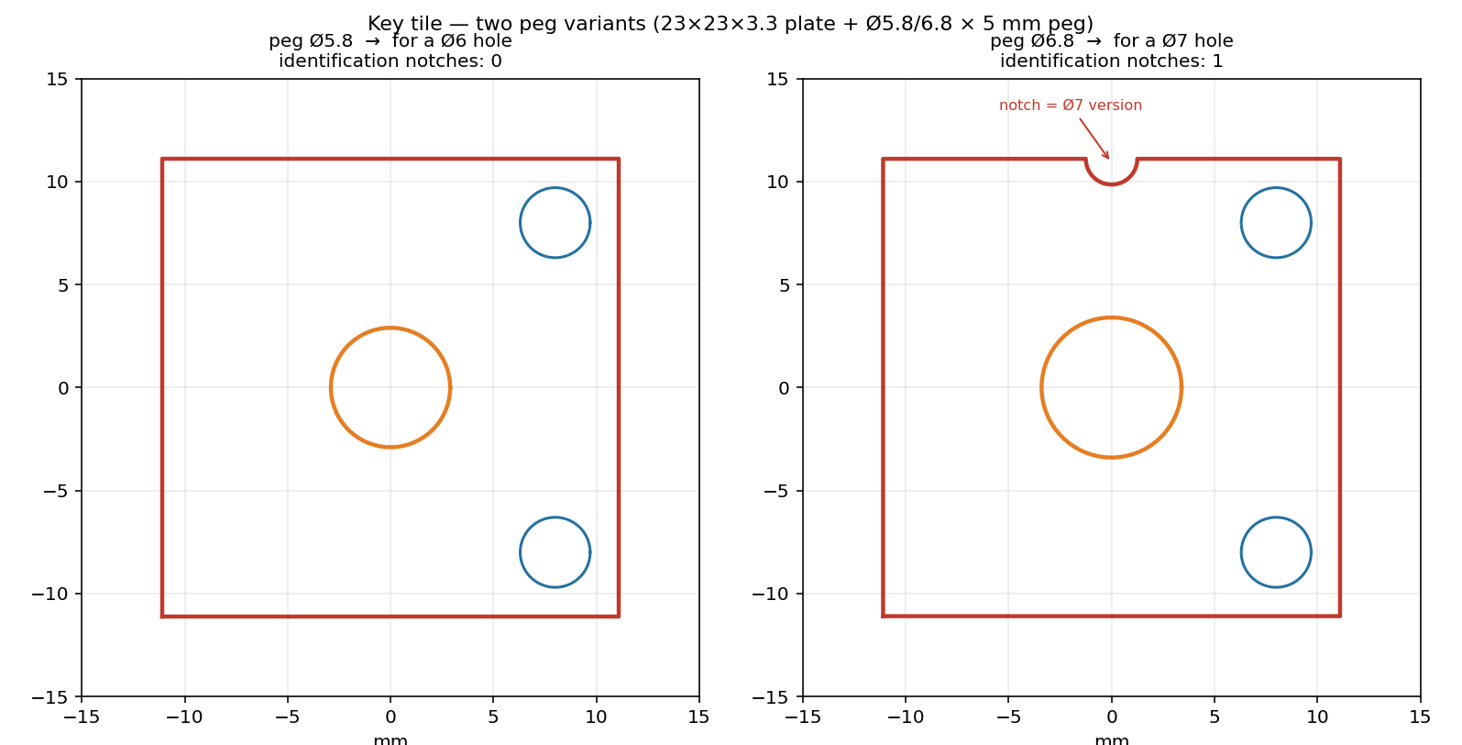
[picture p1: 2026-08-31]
機構/keytile_variants.png

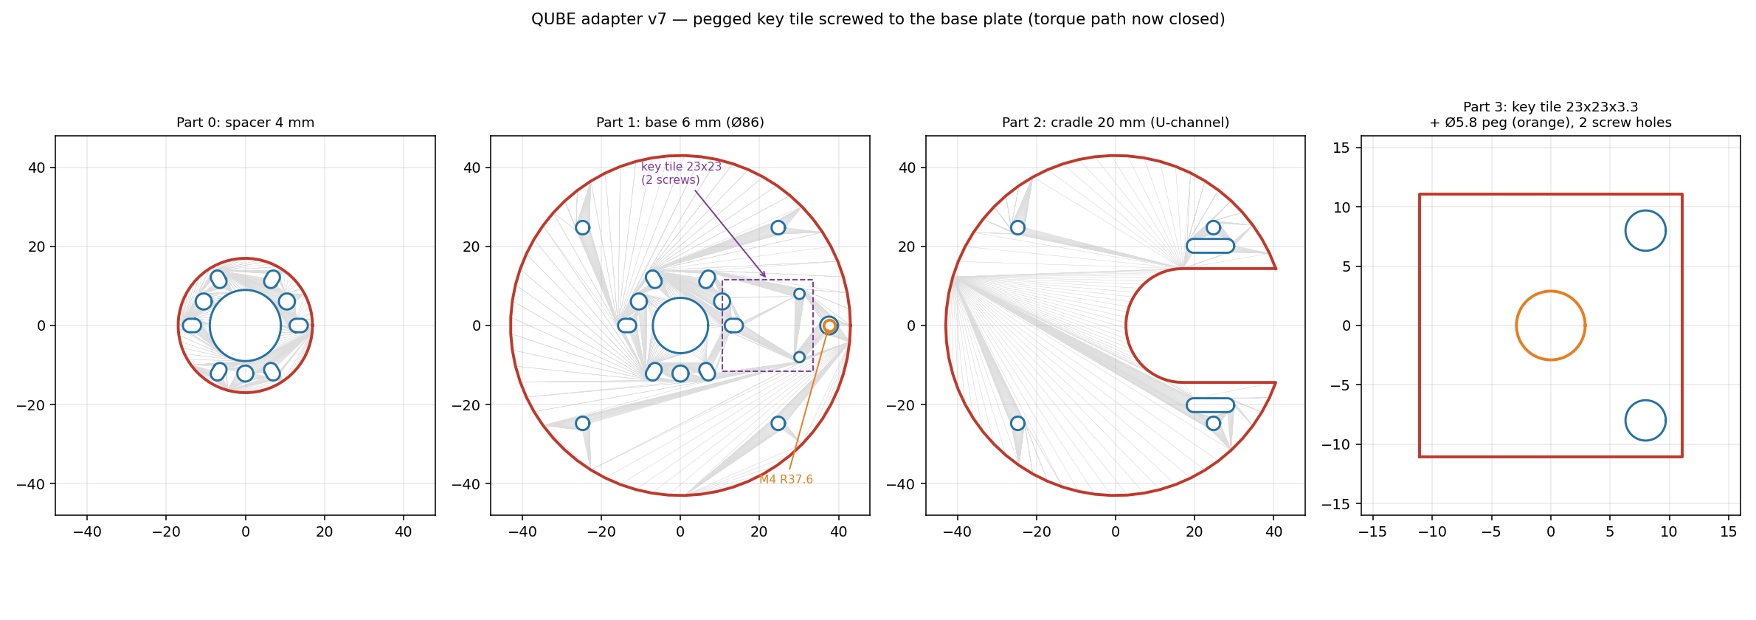
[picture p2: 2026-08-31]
機構/qube_adapter_preview.png

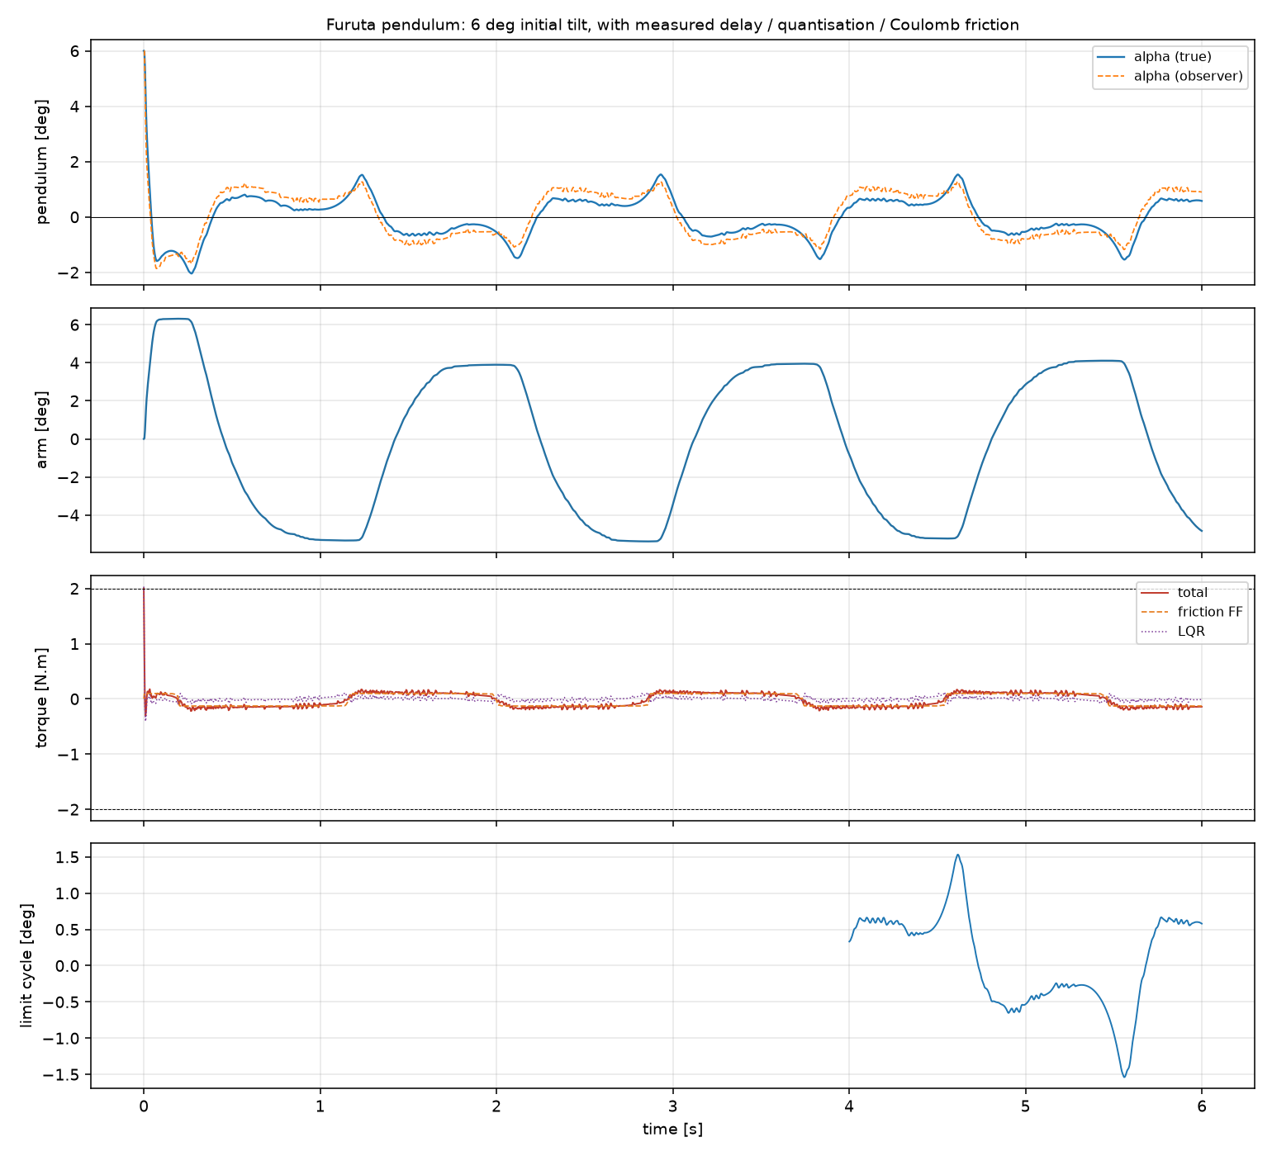
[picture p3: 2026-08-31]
model/simulation.png

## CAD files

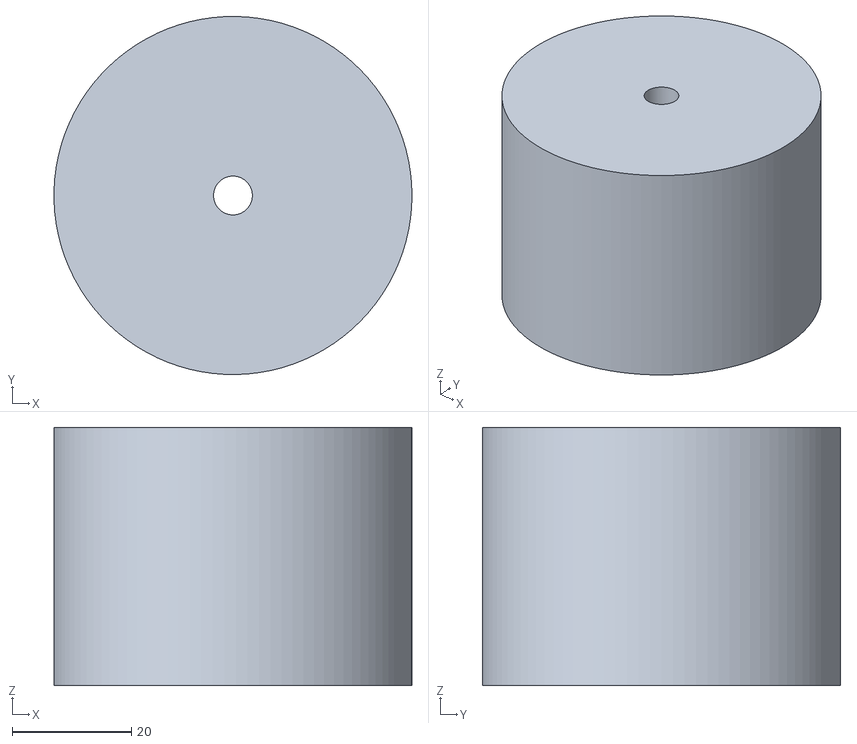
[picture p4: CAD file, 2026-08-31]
機構/calibration_weight_150g.stl
60.0 x 60.0 x 43.3

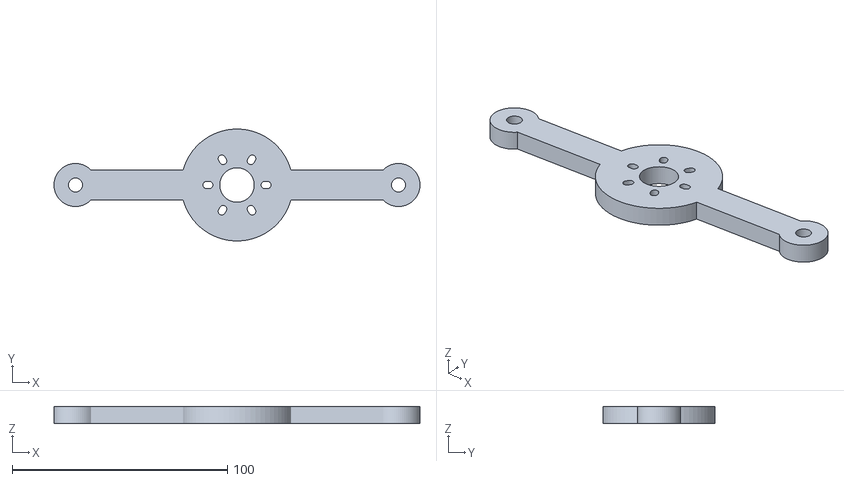
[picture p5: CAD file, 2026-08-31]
機構/calibration_arm.stl
170.0 x 51.9 x 8.00

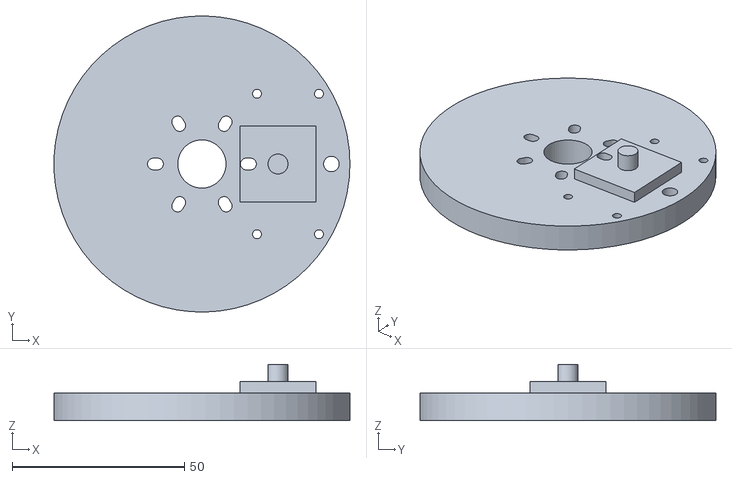
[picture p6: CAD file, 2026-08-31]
機構/qube_adapter_base.stl
85.9 x 86.0 x 16.3

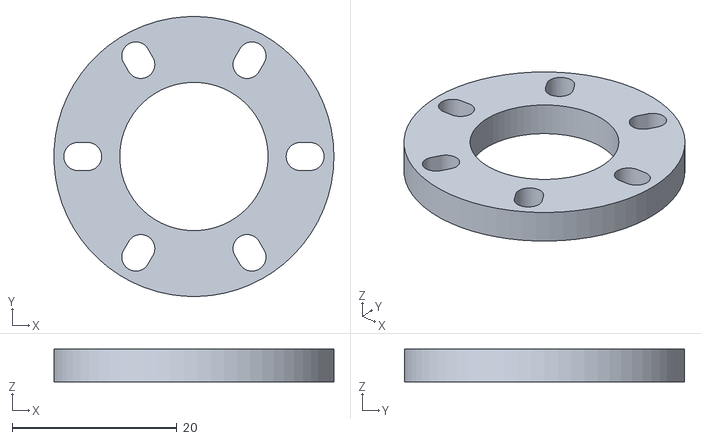
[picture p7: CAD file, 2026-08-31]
機構/qube_adapter_spacer.stl
34.0 x 34.0 x 4.00

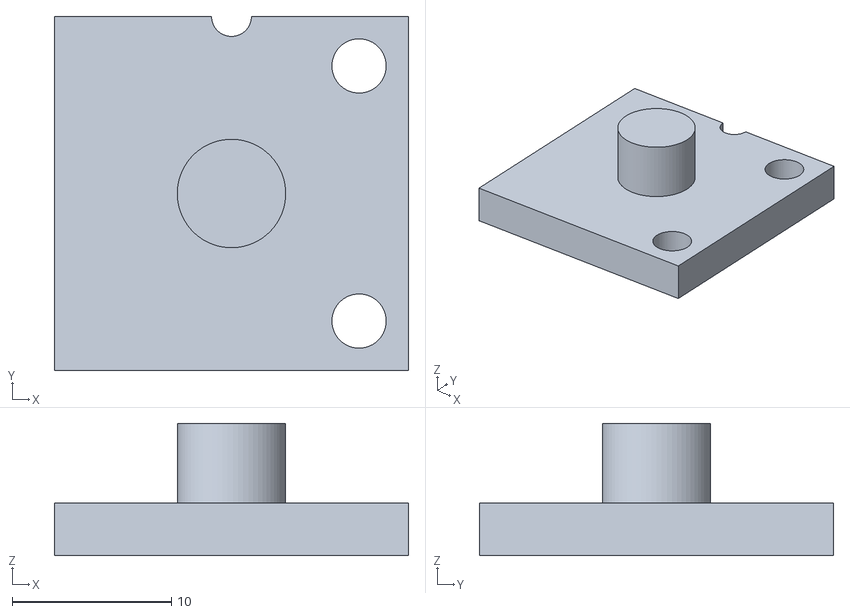
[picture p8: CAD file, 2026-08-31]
機構/qube_adapter_keytile_peg6.8.stl
22.2 x 22.2 x 8.30

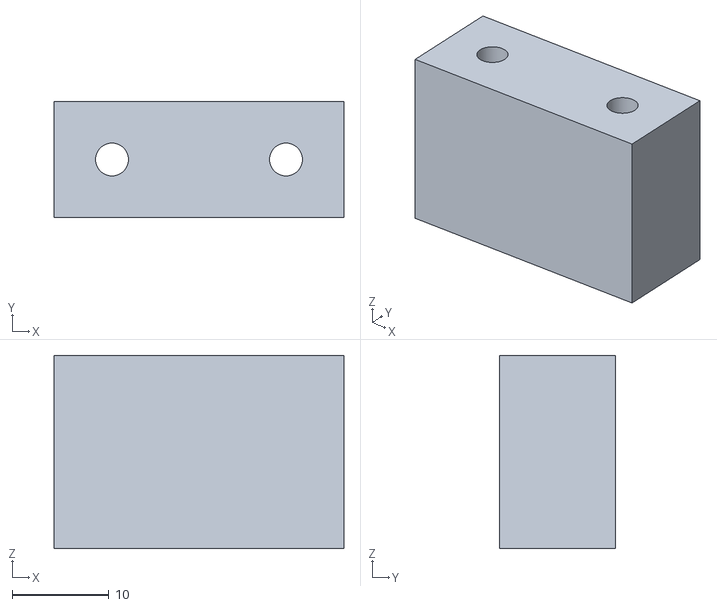
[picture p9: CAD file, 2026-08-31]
機構/qube_adapter_rail.stl
30.0 x 12.0 x 20.0

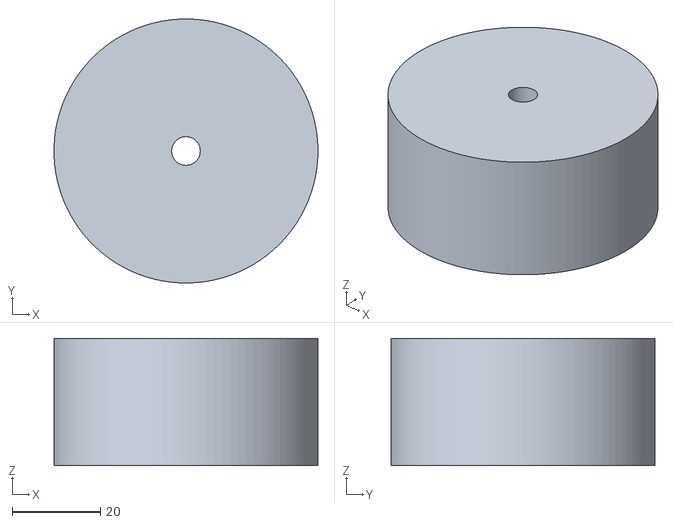
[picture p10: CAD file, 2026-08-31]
機構/calibration_weight_100g.stl
60.0 x 60.0 x 28.9

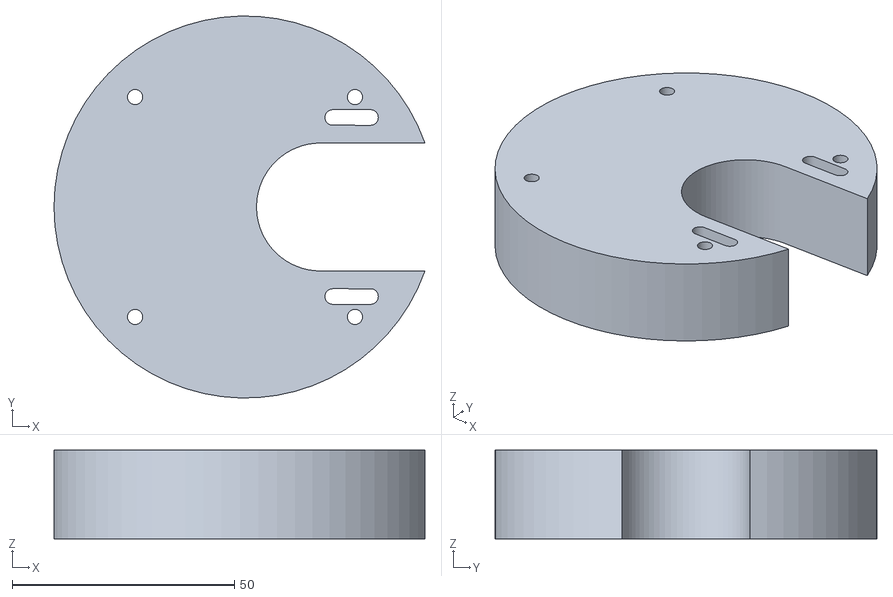
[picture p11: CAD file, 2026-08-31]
機構/qube_adapter_cradle.stl
83.5 x 86.0 x 20.0

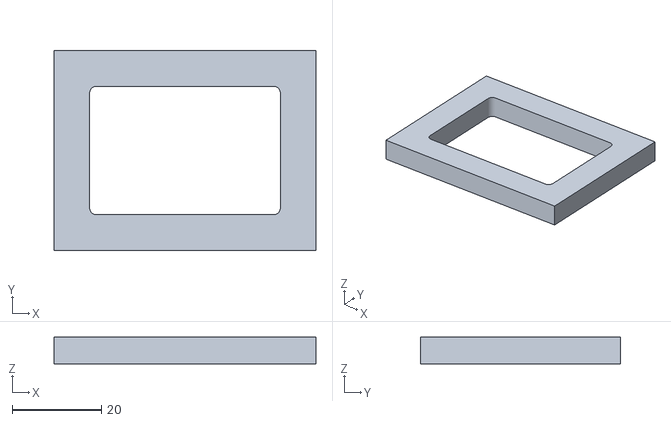
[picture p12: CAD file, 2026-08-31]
機構/qube_adapter_gauge.stl
58.8 x 44.8 x 6.00

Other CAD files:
機構/qube_adapter_keytile_peg5.8.stl

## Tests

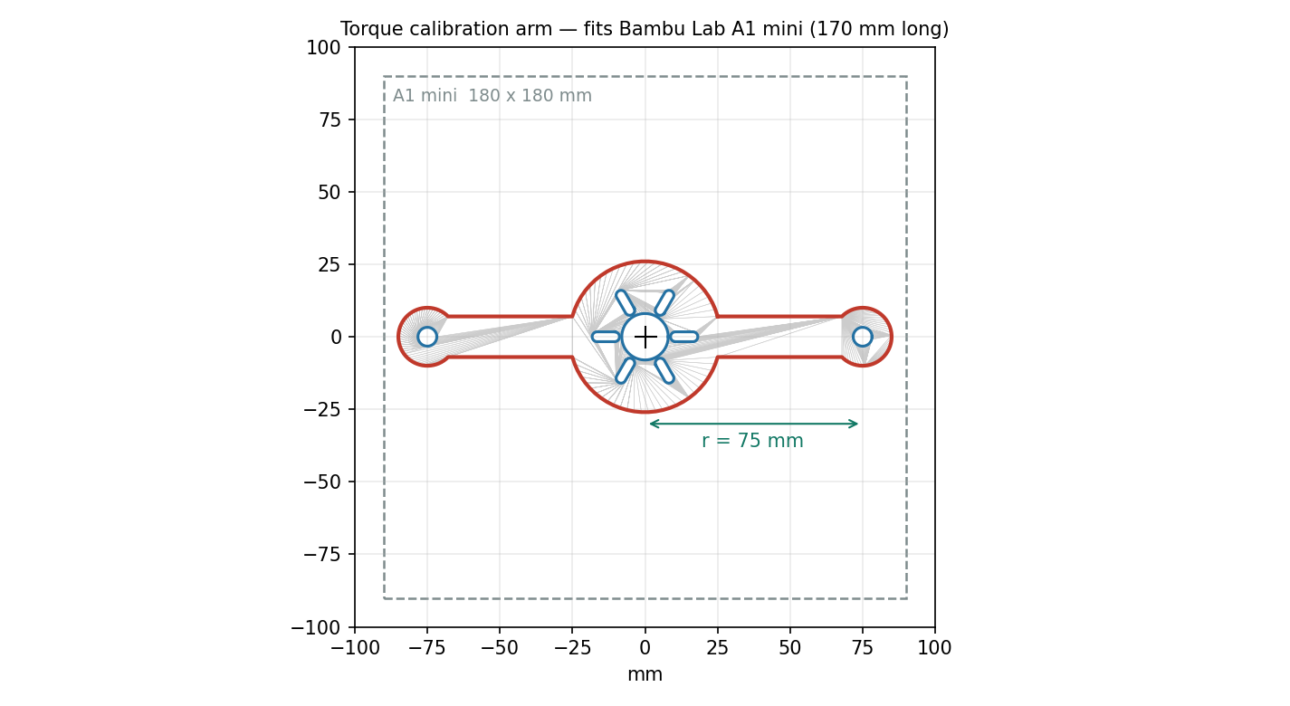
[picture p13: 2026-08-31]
機構/calibration_arm_preview.png

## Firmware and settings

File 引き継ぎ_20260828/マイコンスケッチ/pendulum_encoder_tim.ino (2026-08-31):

// 振子エンコーダ 読み取り + PC送信  【TIM1 ハードウェアエンコーダモード版】
// NUCLEO-G474RE / Arduino IDE (STM32 MCU based boards 3.0.0)
//
// ■ 8/20 指導教員のご指摘により、ソフトウェア割り込み方式から移行したもの
//   「ソフトウェア割り込みはやめたほうがいいです．遅延が大きく，4逓倍で使おうとすると
//     さらに遅延が大きくなるうえに，モータを動かしながらだとノイズによる誤動作が
//     かなり入ります．タイミングを見てTIMエンコーダカウントモードに移行するのが
//     おすすめです．」
//
//   ソフト割り込み版で「取りこぼし無し」を確認したのは【モータを止めた状態】のみ。
//   モータ稼働時のノイズ耐性は未検証だった。TIMのデジタル入力フィルタがその対策になる。
//
// ■ 配線（ソフト割り込み版から A相 だけ D9 → D7 に移動）
//   A相 = D7 (PA8) = TIM1_CH1   ... FT_a   5Vトレラント
//   B相 = D8 (PA9) = TIM1_CH2   ... FT_fda 5Vトレラント
//   5V  = 5V
//   GND = GND
//
//   ※ PA6(D12) / PA7(D11) は TT_a で5Vトレラントではない。絶対に繋がないこと。
//
// ■ カウンタが16bitである件
//   TIM1 は16bit。だが 1kHz でサンプリングして【16bitの差分】を足し込むため、
//   ラップは自然に吸収される。1ms の間に 32768 カウント（16回転）進まない限り厳密。
//   → オーバーフロー割り込みは不要。int32 累積という要件はそのまま満たされる。

#include <Arduino.h>

// ---- 立ち上げ用フラグ ----
//  true  : シリアルモニタで読めるテキスト出力（配線確認・立ち上げ用）
//  false : 本番の13バイトバイナリフレーム
bool textMode = false;

// ---- 入力フィルタの強さ（0〜15）----
//  15 で最も強い。TIM1クロック170MHz、CKD=DIV1 のとき
//  f_SAMPLING = 170MHz/32 = 5.3MHz を8回連続で同じ値、つまり約1.5µs より短いヒゲを捨てる。
//  こちらのエッジ間隔は最速時でも約120µs あるので、15 にしても信号は削られない。
//  モータ稼働時にカウントが暴れるようなら、まずここを疑う（下げる理由は基本的に無い）。
const uint32_t ENC_FILTER = 0xF;

TIM_HandleTypeDef htim_enc;

void encoderInit() {
  __HAL_RCC_GPIOA_CLK_ENABLE();
  __HAL_RCC_TIM1_CLK_ENABLE();

  GPIO_InitTypeDef g = {0};
  g.Pin       = GPIO_PIN_8 | GPIO_PIN_9;
  g.Mode      = GPIO_MODE_AF_PP;
  g.Pull      = GPIO_NOPULL;          // エンコーダはプッシュプル出力なのでプル不要
  g.Speed     = GPIO_SPEED_FREQ_HIGH;
  g.Alternate = GPIO_AF6_TIM1;        // PeripheralPins.c で確認済み
  HAL_GPIO_Init(GPIOA, &g);

  htim_enc.Instance               = TIM1;
  htim_enc.Init.Prescaler         = 0;
  htim_enc.Init.CounterMode       = TIM_COUNTERMODE_UP;
  htim_enc.Init.Period            = 0xFFFF;
  htim_enc.Init.ClockDivision     = TIM_CLOCKDIVISION_DIV1;
  htim_enc.Init.RepetitionCounter = 0;
  htim_enc.Init.AutoReloadPreload = TIM_AUTORELOAD_PRELOAD_DISABLE;

  TIM_Encoder_InitTypeDef e = {0};
  e.EncoderMode  = TIM_ENCODERMODE_TI12;      // TI1・TI2 の両エッジ = 4逓倍
  e.IC1Polarity  = TIM_ICPOLARITY_RISING;
  e.IC1Selection = TIM_ICSELECTION_DIRECTTI;
  e.IC1Prescaler = TIM_ICPSC_DIV1;
  e.IC1Filter    = ENC_FILTER;
  e.IC2Polarity  = TIM_ICPOLARITY_RISING;
  e.IC2Selection = TIM_ICSELECTION_DIRECTTI;
  e.IC2Prescaler = TIM_ICPSC_DIV1;
  e.IC2Filter    = ENC_FILTER;

  HAL_TIM_Encoder_Init(&htim_enc, &e);
  TIM1->CNT = 0;
  HAL_TIM_Encoder_Start(&htim_enc, TIM_CHANNEL_ALL);
}

// ---- 1 kHz サンプリング ----
HardwareTimer *sampleTimer;

volatile int32_t  count   = 0;
static   uint16_t prevCnt = 0;

volatile int32_t  s_count = 0;
volatile uint32_t s_t_us  = 0;
volatile uint16_t s_seq   = 0;
volatile bool     s_ready = false;

void onSample() {
  uint16_t now = (uint16_t)TIM1->CNT;
  count  += (int16_t)(now - prevCnt);   // ★16bitの差にキャストするのが肝。ラップを吸収する
  prevCnt = now;

  s_count = count;
  s_t_us  = micros();
  s_seq++;
  s_ready = true;
}

// CRC-8 (多項式 0x07, 初期値 0x00)  ※PC側もこれに合わせること
uint8_t crc8(const uint8_t *p, size_t n) {
  uint8_t c = 0x00;
  for (size_t i = 0; i < n; i++) {
    c ^= p[i];
    for (uint8_t b = 0; b < 8; b++)
      c = (c & 0x80) ? (uint8_t)((c << 1) ^ 0x07) : (uint8_t)(c << 1);
  }
  return c;
}

void setup() {
  Serial.begin(921600);     // 13B x 1kHz = 130 kbit/s。115200 では足りない

  encoderInit();
  prevCnt = (uint16_t)TIM1->CNT;

  sampleTimer = new HardwareTimer(TIM6);   // 他で使われていたら TIM7 に変える
  sampleTimer->setOverflow(1000, HERTZ_FORMAT);
  sampleTimer->attachInterrupt(onSample);
  sampleTimer->resume();
}

void loop() {
  if (!s_ready) return;

  int32_t  c  = s_count;
  uint32_t t  = s_t_us;
  uint16_t sq = s_seq;
  s_ready = false;

  if (textMode) {
    static uint32_t lastPrint = 0;
    if (millis() - lastPrint >= 50) {          // 20 Hz に間引いて表示
      lastPrint = millis();
      Serial.print(c);
      Serial.print("  ");
      Serial.println(c * 360.0 / 2048.0, 2);   // 確認用の度表示。本番では送らない
    }
  } else {
    uint8_t f[13];
    f[0]  = 0xA5;  f[1]  = 0xA5;
    f[2]  =  sq        & 0xFF;  f[3]  = (sq >>  8) & 0xFF;
    f[4]  =  t         & 0xFF;  f[5]  = (t  >>  8) & 0xFF;
    f[6]  = (t  >> 16) & 0xFF;  f[7]  = (t  >> 24) & 0xFF;
    f[8]  =  c         & 0xFF;  f[9]  = (c  >>  8) & 0xFF;
    f[10] = (c  >> 16) & 0xFF;  f[11] = (c  >> 24) & 0xFF;
    f[12] = crc8(f, 12);
    Serial.write(f, 13);
  }
}

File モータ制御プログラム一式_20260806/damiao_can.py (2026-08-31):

"""
Damiao DM-J4310-2EC V1.1 を Python から CAN 経由で制御するモジュール

2026/8/6 の動作検証で実際に動作を確認した内容をまとめたもの。
メンバーA

必要なもの:
    pip install python-can pyserial

構成:
    PC --USB--> USB-CAN Analyzer --CAN_H/CAN_L--> モータ
                                  24V電源 -------> モータ

使い方:
    from damiao_can import Motor
    with Motor(port="COM3", motor_id=4) as m:
        print(m.read_status())
        m.spin(speed=0.5, duration=12.6)   # 0.5 rad/s で 1 回転
"""

import time
import struct
import math
import can

# ---- モータの特殊コマンド（モータIDあてに送る）----------------------------
# 注意: これらは 0x104 や 0x204 では受け付けられない。必ずモータIDあてに送ること。
CMD_ENABLE  = bytes([0xFF] * 7 + [0xFC])   # 使能（通電。LEDが緑になる）
CMD_DISABLE = bytes([0xFF] * 7 + [0xFD])   # 失能（非通電。LEDが赤。安全な状態）

# ---- パラメータ読み書き用 --------------------------------------------------
PARAM_CAN_ID  = 0x7FF   # パラメータ操作はこのIDあてに送る
PARAM_READ    = 0x33
PARAM_WRITE   = 0x55
PARAM_SAVE    = 0xAA    # フラッシュ保存（電源を切っても設定が残る）
RID_CTRL_MODE = 10      # 制御モードのパラメータ番号

MODE_MIT      = 1
MODE_POS_VEL  = 2
MODE_VELOCITY = 3
MODE_NAMES = {1: "MIT", 2: "POS-VEL", 3: "VELOCITY"}

# ---- MITモードの値域（フレームに詰めるときの換算に使う）--------------------
P_MAX, V_MAX, T_MAX = 12.5, 30.0, 10.0
KP_MAX, KD_MAX = 500.0, 5.0


def _float_to_uint(x, lo, hi, bits):
    """浮動小数を、指定ビット数の整数に線形変換する"""
    x = max(min(x, hi), lo)
    return int((x - lo) * ((1 << bits) - 1) / (hi - lo))


def _uint_to_float(x, lo, hi, bits):
    """上の逆変換"""
    return x / ((1 << bits) - 1) * (hi - lo) + lo


class Motor:
    """DM-J4310-2EC V1.1 を1台制御する"""

    def __init__(self, port="COM3", motor_id=4, bitrate=1_000_000, serial_baud=2_000_000):
        self.motor_id = motor_id
        self.bus = can.Bus(
            interface="seeedstudio",   # USB-CAN Analyzer 用のバックエンド
            channel=port,
            bitrate=bitrate,           # CANのボーレート。モータ側は 1Mbps 固定
            baudrate=serial_baud,      # アダプタとPC間のシリアル速度
            frame_type="STD",          # 標準フレーム
            operation_mode="normal",
        )
        # 重要: 開いた直後に送信すると応答を取りこぼす。必ず待つこと。
        time.sleep(0.5)
        for _ in range(3):
            self.bus.recv(timeout=0.05)

    # -- 後始末 --------------------------------------------------------------
    def __enter__(self):
        return self

    def __exit__(self, *exc):
        self.close()

    def close(self):
        """必ず失能させてから閉じる"""
        try:
            self.disable()
        except Exception:
            pass
        self.bus.shutdown()

    # -- 低レベル ------------------------------------------------------------
    def _send(self, can_id, data):
        self.bus.send(can.Message(arbitration_id=can_id, data=data, is_extended_id=False))

    @staticmethod
    def _decode(data):
        """モータからのフィードバックフレームを解釈する"""
        if len(data) < 8:
            return None
        return {
            "id":       data[0] & 0x0F,
            "err":      (data[0] >> 4) & 0x0F,   # 0=正常、8〜E=故障、1=使能中
            "pos_raw":  (data[1] << 8) | data[2],
            "vel_raw":  (data[3] << 4) | (data[4] >> 4),
            "tau_raw":  ((data[4] & 0x0F) << 8) | data[5],
            "temp_mos": data[6],                  # ドライバ温度
            "temp_rot": data[7],                  # モータ内部温度
        }

    # -- 状態の取得 ----------------------------------------------------------
    def read_status(self, tries=20):
        """
        モータの状態を読む。動作させない安全な DISABLE を送って応答を得る方式。
        通信確認にも使える。応答が無ければ None（電源が入っていない可能性）。
        """
        for _ in range(tries):
            self._send(self.motor_id, CMD_DISABLE)
            time.sleep(0.05)
            msg = self.bus.recv(timeout=0.3)
            if msg:
                fb = self._decode(msg.data)
                if fb:
                    fb["pos_rad"] = _uint_to_float(fb["pos_raw"], -P_MAX, P_MAX, 16)
                    return fb
            time.sleep(0.05)
        return None

    def scan(self, id_range=range(1, 9)):
        """CAN IDを順に叩いて、応答するモータを探す"""
        found = {}
        for cid in id_range:
            self._send(cid, CMD_DISABLE)
            t0 = time.time()
            while time.time() - t0 < 0.15:
                msg = self.bus.recv(timeout=0.05)
                if msg:
                    found[cid] = self._decode(msg.data)
                    break
        return found

    # -- 使能／失能 ----------------------------------------------------------
    def enable(self):
        """通電する。LEDが緑になる"""
        self._send(self.motor_id, CMD_ENABLE)
        time.sleep(0.1)

    def disable(self):
        """通電を切る。LEDが赤に戻る。安全な状態"""
        self._send(self.motor_id, CMD_DISABLE)
        time.sleep(0.05)

    # -- 制御モードの読み書き ------------------------------------------------
    def read_mode(self):
        """現在の制御モードを読む（1=MIT, 2=位置速度, 3=速度）"""
        d = bytes([self.motor_id & 0xFF, (self.motor_id >> 8) & 0xFF,
                   PARAM_READ, RID_CTRL_MODE, 0, 0, 0, 0])
        self._send(PARAM_CAN_ID, d)
        t0 = time.time()
        while time.time() - t0 < 0.5:
            msg = self.bus.recv(timeout=0.1)
            if msg and len(msg.data) >= 8 \
               and msg.data[2] == PARAM_READ and msg.data[3] == RID_CTRL_MODE:
                return struct.unpack("<I", msg.data[4:8])[0]
        return None

    def set_mode(self, mode, save=True):
        """
        制御モードを変更する。save=True でフラッシュに保存し、電源を切っても維持される。
        変更が反映されたか読み返して確認し、成功なら True を返す。
        """
        self.disable()   # 念のため失能させてから変更する
        d = bytes([self.motor_id & 0xFF, (self.motor_id >> 8) & 0xFF,
                   PARAM_WRITE, RID_CTRL_MODE]) + struct.pack("<I", mode)
        self._send(PARAM_CAN_ID, d)
        time.sleep(0.2)

        if self.read_mode() != mode:
            return False

        if save:
            d = bytes([self.motor_id & 0xFF, (self.motor_id >> 8) & 0xFF,
                       PARAM_SAVE, 0x01, 0, 0, 0, 0])
            self._send(PARAM_CAN_ID, d)
            time.sleep(0.3)
        return True

    # -- 速度モードでの制御（一定速度で回すならこれが一番簡単）--------------
    def set_velocity(self, speed_rad_s):
        """速度指令を1回送る。速度モードのときのみ有効"""
        self._send(0x200 + self.motor_id, struct.pack("<f", speed_rad_s))

    def spin(self, speed=0.5, duration=None, turns=None, verbose=True):
        """
        速度モードで回す。

            speed    : 回転速度 [rad/s]。正で一方向、負で逆方向
            duration : 回す秒数。turns を指定した場合は不要
            turns    : 回転数。duration の代わりに指定できる
            戻り値   : 実際に回った角度 [deg]

        安全のため、終了時・例外時ともに必ず速度0→失能する。
        """
        if duration is None:
            if turns is None:
                raise ValueError("duration か turns のどちらかを指定してください")
            duration = abs(turns * 2 * math.pi / speed)

        cmd = struct.pack("<f", speed)
        total = 0.0      # エンコーダの一周をまたいでも累積できるようにする
        prev = None
        last = None

        try:
            self.enable()
            if verbose:
                print(">> %.2f rad/s で %.1f 秒 回転" % (speed, duration))
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

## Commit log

2026-08-31 回転型倒立振子（Furuta pendulum）一式
    2026/08/28 時点。スイングアップから倒立保持まで動作する状態。
    - 成功率 82.8%（トルク上限 0.8 N·m、29回）、倒立保持 最長 61.6 秒
    - model/ 運動方程式の導出と LQR・カルマンゲインの設計（Python、オフライン専用）
    - csharp/ 制御プログラム本体（SwingUp / BalanceControl ほか）。テスト 88 件合格
    - 機構/ アダプタの STL と生成スクリプト
    - 引き継ぎ_20260828/ 経緯と実測値の全記録、動作確認済みコードのスナップショット
    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
    [calibration_arm.stl, calibration_weight_100g.stl, calibration_weight_150g.stl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]
2026-08-31 引継ぎメモから公開しない節を削除し、研究室の方の実名を伏せた
    - 「作業日程」（メンバー個人の予定）を削除。メモ自身に「この個人予定は
    先生提出資料には書かないこと」と明記されているため
    - §10「先生とのやり取りのルール」を削除。内部運用メモのため
    - 3Dプリンタ対応の研究室の方3名の実名を研究室の方A/B/Cに置換。
    初回の置換リストから漏れていた
2026-09-06 発表用の A0 ポスターを追加
    - ポスター/倒立振子_A0ポスター.html … A0 縦 1 枚。8 節構成で、
    運動方程式・パラメータ同定・線形化・制御器設計・実験結果までを収める。
    図は SVG 直書きなので外部依存なし。@page で A0 縦を指定してあり、
    ブラウザの印刷からそのまま出力できる
    - 図3/図5/図6/図7 は作業報告と trial_log_20260828.csv の実測値から作図
    - ポスター/倒立振子_ポスターレイアウト案.html … 面積配分を決めたワイヤーフレーム
